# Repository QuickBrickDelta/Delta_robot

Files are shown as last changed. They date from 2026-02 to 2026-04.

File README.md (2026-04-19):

# QuickBrick Delta Robot 




> Projet de session S4 — Baccalauréat en Génie Robotique, Université de Sherbrooke.  
> Un système complet de tri automatisé par vision numérique et planification de trajectoire optimale.

Réalisé par  Domenic Coppola, Antoine Côté, Thierry Allen, Antoine Bolduc et Raphaël Gendron.

Utilisation de l'IA générative à des fins de déverminage et d'assistance à la conception.

---

##  Aperçu

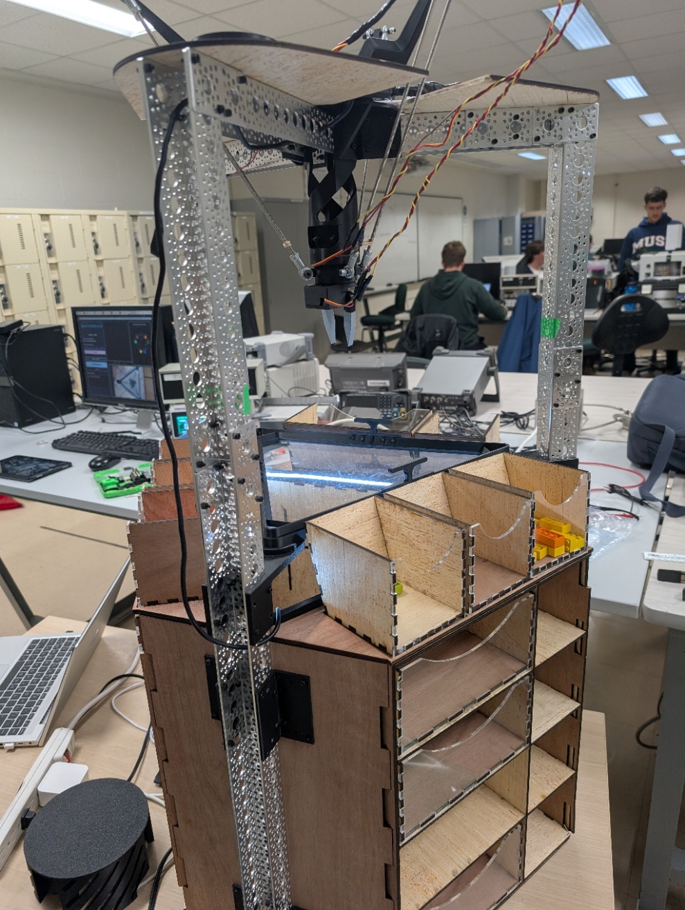
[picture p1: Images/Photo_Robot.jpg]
robot


| Interface Vision | Planification de Trajectoire |
|:---:|:---:|
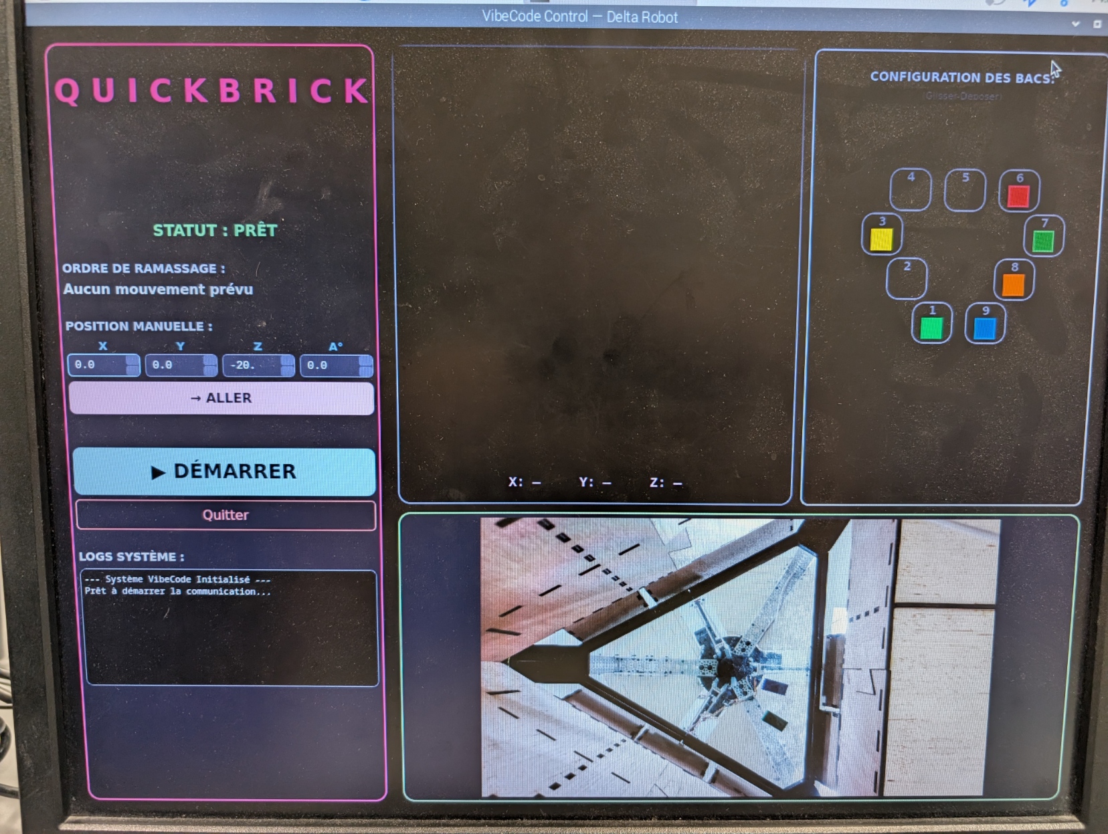
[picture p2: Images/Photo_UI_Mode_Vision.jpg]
vision
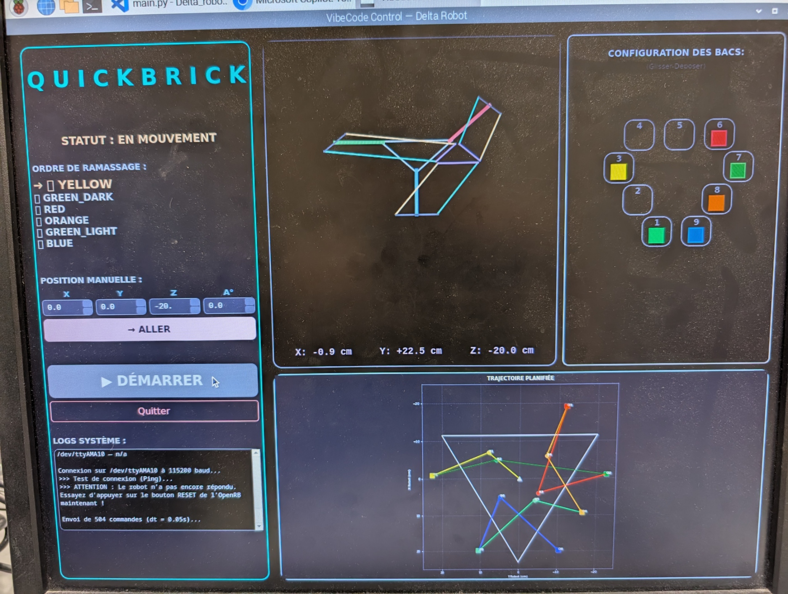
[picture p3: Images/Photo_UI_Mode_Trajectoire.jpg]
traj
|  |  |

---

##  Mise en route rapide

### 1. Installation du logiciel
Clonez le dépôt et installez les dépendances :
```bash
git clone https://github.com/votre-repo/Delta_robot.git
cd Delta_robot
pip install -r requirements.txt
```
Consultez le [Guide d'installation détaillé](docs/software_setup.md) pour la configuration du Raspberry Pi et de la caméra.

### 2. Matériel
Ce projet utilise des moteurs **Dynamixel XC430** et un contrôleur **OpenRB-150**.
Voir la [Documentation Matérielle](docs/hardware.md) pour le schéma de câblage et la liste des composants (BOM).

---

##  Architecture du projet

Le robot intègre plusieurs sous-systèmes travaillant en boucle fermée :

1.  **Vision Numérique** : Détection des blocs et conversion pixel → cm via homographie.
2.  **Planificateur** : Optimisation de l'ordre de tri par algorithme **Branch & Bound** (Problème du voyageur de commerce asymétrique).
3.  **Cinématique** : Modèle géométrique inverse pour le pilotage des 3 bras parallèles.
4.  **UI de Contrôle** : Visualisation 3D en temps réel et interface de configuration des bacs par "Drag & Drop".

###  Structure des dossiers
```
Delta_robot/
├── Arduino/            # Firmware C++ pour OpenRB-150
├── CAD/                # Fichiers CAD (STL et DXF) d'impression 3D et découpe laser
├── CinématiqueRobot/   # Modèles DGM/IGM & Interpolations
├── Communication/      # Protocole série Raspberry Pi ↔ Arduino
├── docs/               # Documentation détaillée (Hardware, Math, Setup)
├── Images/             # Captures et photos du système
├── Trajectoire/        # Algorithmes d'optimisation (BnB, TSP)
├── UI/                 # Interface PyQt6 (VibeCode UI)
└── VisionNumerique/    # Traitement d'image OpenCV & HSV
```

---

##  Documentation détaillée

*   [**Guide Matériel**](docs/hardware.md) : Liste des pièces, électronique et montage.
*   [**Fichiers CAD**](CAD/readme-cad.md) : Fichiers CAD des pièces destinées à l'impression 3D et la découpe laser.
*   [**Installation Logicielle**](docs/software_setup.md) : Configuration de l'environnement Python et flashage Arduino.
*   [**Mathématiques & Cinématique**](docs/kinematics.md) : Détails sur l'IGM et la planification de trajectoire.
*   [**Contribuer**](CONTRIBUTING.md) : Comment aider à améliorer le projet.

---

##  Licence

Ce projet est distribué sous la licence **MIT**. Voir le fichier [LICENSE.txt](LICENSE.txt) pour plus de détails.

---

*Université de Sherbrooke — GRO S4 — 2025-2026*

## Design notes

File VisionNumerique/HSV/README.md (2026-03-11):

## VisionNumerique/HSV

Objectif: regrouper les scripts dont la stratégie couleur est **majoritairement HSV**
(plus robuste aux variations de luminosité que des seuils RGB).

### Calibration HSV (ROI)

Lance:

```bash
python VisionNumerique/HSV/calibrate_hsv_ranges.py
```

Usage:
- **Drag** une ROI sur un bloc
- **1..9** assigne la dernière ROI à une couleur (ex: `1=red`, `2=green`, ...)
- **e** exporte `hsv_ranges.json` dans ce dossier
- **r** reset, **q/ESC** quitter

Le fichier `hsv_ranges.json` contient des plages HSV OpenCV \(H 0..179\) sous forme
de liste d'intervalles `[[loHSV],[hiHSV]]`. Le rouge peut être exporté en **2 intervalles** (wrap autour de 0).

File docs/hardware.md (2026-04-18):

# Documentation Matérielle

Ce guide couvre l'assemblage physique, l'électronique et la liste des composants (BOM) du Robot Delta.

## Liste des composants à acheter (BOM)
| Image | Composant | Description | Quantité |
|---|---|---|---|
|  | **Moteurs** | Dynamixel XC430-W240 (ou équivalent) | 3 |
|  | **Contrôleur** | OpenRB-150 (compatible Arduino) | 1 |
|  | **Alimentation** | Bloc DC 12V 5A | 1 |
|  | **Joint à rotule** | Joint à rotule fileté M4 | 12 |
|  | **Tiges** | Tige filetée M4-30mm | 6 |
|  | **Caméra** | Caméra module 3 Raspberry Pi | 1 |
|  | **Servo moteur SG90** | Servo moteur SG90 | 2 |
|  | **Bande lumineuse de DEL** | À connexion USB (5V), intensité variable | 1 |
|  | **Attache à tiroir** | Attache à tiroir Richelieu | 1 |
|  | **Fil caméra** | Fil 22 pin à 15 pin pour caméra Raspberry Pi | 1 |
|  | **Extrudé 9 pouces** | Extrudé 9 pouces | 3 |
|  | **Extrudé 12 pouces** | Extrudé 12 pouces | 3 |
|  | **Extrudé 24 pouces** | Extrudé 24 pouces | 3 |
|  | **Plaque pour extrudés** | Plaque connecteur pour extrudés | 12 |
|  | **Convertisseur buck** | Convertisseur buck 12V à 5V | 1 |
|  | **Feuille d'acrylique** | Plaque d'acrylique 3mm | 1 |
|  | **Plaques de bois (découpe laser)** | Plaques de bois 4.3mm — utiliser les retailles lorsque possible | 8 |

## Schéma de câblage

1.  **Moteurs Dynamixel** : Connectez les 3 moteurs en "daisy-chain" et reliez-les à l'un des ports Dynamixel de l'OpenRB-150.
2.  **Alimentation** : Connectez le bloc 12V au bornier de l'OpenRB-150. **ATTENTION** : Vérifiez la polarité.
3.  **Communication** : Reliez l'OpenRB-150 au Raspberry Pi (ou PC) via un câble USB-C.

Schéma électrique

Schéma Électrique
*(Fichier draw.io)*

## Étapes d'assemblage

1.  **Base** : Montez les 3 moteurs Dynamixel à 120° sur le châssis principal.
2.  **Parallélogrammes** : Assemblez les 6 tiges parallèles à l'aide des joints à rotule.
3.  **Effecteur** : Montez l'effecteur final (pince) et connectez le signal du servo aux broches de l'OpenRB-150.
4.  **Calibration** : Assurez-vous que les moteurs sont à 0° (horizontaux) avant de fixer les bras principaux.

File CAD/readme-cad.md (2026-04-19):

# Fichiers CAD — QuickBrick Delta

Les fichiers CAD de ce projet ont été conçus dans [OnShape](https://cad.onshape.com/).

> [Voir l'assemblage complet](https://cad.onshape.com/documents/0e918514191409c2a18572ab/w/21e7121afbe0440ffe943c21/e/87bd8cfb125acff7d4804a25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)

---

## Formats disponibles

- **STL** — Prêt pour l'impression 3D
- **DXF** — Prêt pour la découpe laser

---

## Impression 3D

### Bras robotique



| Image | Pièce | Fichier STL | Matériau recommandé | Remplissage | Quantité |
|---|---|---|---|---|---|
|  | Plateforme supérieure | [plateforme-superieure.stl](STL/assemblage-robot/plateforme-superieure.stl) | PLA | 15% | 1 |
|  | Coque | [coque.stl](STL/assemblage-robot/coque.stl) | PLA | 15% | 1 |
|  | Système de mise à l'origine | [mise-a-lorigine.stl](STL/assemblage-robot/mise-a-lorigine.stl) | PLA | 15% | 1 |
|  | Anneau bearing | [anneau-bearing.stl](STL/assemblage-robot/anneau-bearing.stl) | PLA | 15% | 3 |
|  | Clip bearing | [clip-bearing.stl](STL/assemblage-robot/clip-bearing.stl) | PLA | 15% | 3 |
|  | Biceps | [biceps.stl](STL/assemblage-robot/biceps.stl) | PLA | 15% | 3 |
|  | Espaceur | [espaceur.stl](STL/assemblage-robot/espaceur.stl) | PLA | 15% | 24 |

---

### Plaque d'acrylique



| Image | Pièce | Fichier STL | Matériau recommandé | Remplissage | Quantité |
|---|---|---|---|---|---|
|  | Supports à plaque d'acrylique | [support-plaque-acrylique.stl](STL/plaque-acrylique/support-plaque-acrylique.stl) | PLA | 15% | 3 |
|  | Bordure | [bordure.stl](STL/plaque-acrylique/bordure.stl) | PLA | 15% | 3 |
|  | Poignée | [poignee.stl](STL/plaque-acrylique/poignee.stl) | PLA | 15% | 3 |

---

### Pince



| Image | Pièce | Fichier STL | Matériau recommandé | Remplissage | Quantité |
|---|---|---|---|---|---|
|  | Support à servo de poignet | [support-servo-poignet.stl](STL/pince/support-servo-poignet.stl) | PLA | 15% | 1 |
|  | Support à servo de pince | [support-servo-pince.stl](STL/pince/support-servo-pince.stl) | PLA | 15% | 1 |
|  | Plaque pour support à servo de pince | [plaque-support-servo-pince.stl](STL/pince/plaque-support-servo-pince.stl) | PLA | 15% | 1 |
|  | Washer pour pince | [washer-pince.stl](STL/pince/washer-pince.stl) | PLA | 15% | 1 |
|  | Pince 1 | [pince-1.stl](STL/pince/pince-1.stl) | PLA | 15% | 1 |
|  | Pince 2 | [pince-2.stl](STL/pince/pince-2.stl) | PLA | 15% | 1 |
|  | Embouts de pince | [embouts-pince.stl](STL/pince/embouts-pince.stl) | TPU | 15% | 2 |
|  | Couvercle de pince avec couronne pour mise à l'origine | [couvercle-pince-couronne.stl](STL/pince/couvercle-pince-couronne.stl) | PLA | 15% | 1 |

---

### Anneau de lumière



| Image | Pièce | Fichier STL | Matériau recommandé | Remplissage | Quantité |
|---|---|---|---|---|---|
|  | Anneau de lumière - Pièce 1 | [anneau-lumiere-1.stl](STL/anneau-lumiere/anneau-lumiere-1.stl) | PLA | 15% | 6 |
|  | Anneau de lumière - Pièce 2 | [anneau-lumiere-2.stl](STL/anneau-lumiere/anneau-lumiere-2.stl) | PLA | 15% | 6 |
|  | Anneau de lumière - Pièce 3 | [anneau-lumiere-3.stl](STL/anneau-lumiere/anneau-lumiere-3.stl) | PLA | 15% | 6 |

---

### Attaches de caméra et Raspberry Pi



| Image | Pièce | Fichier STL | Matériau recommandé | Remplissage | Quantité |
|---|---|---|---|---|---|
|  | Attache caméra | [attache-camera.stl](STL/autres/attache-camera.stl) | PLA | 15% | 1 |
|  | Attache Raspberry Pi | [attache-raspberry-pi.stl](STL/autres/attache-raspberry-pi.stl) | PLA | 15% | 1 |

---

## Découpe laser

### Étagère



| Image | Pièce | Fichier STL | Fichier DXF | Matériau | Épaisseur | Quantité |
|---|---|---|---|---|---|---|
|  | Montant de support | [montant-support.stl](STL/etagere/montant-support.stl) | [montant-support.dxf](DXF/etagere/montant-support.dxf) | Bois | 4.3mm | 2 |
|  | Montant de support avec trou | [montant-support-trou.stl](STL/etagere/montant-support-trou.stl) | [montant-support-trou.dxf](DXF/etagere/montant-support-trou.dxf) | Bois | 4.3mm | 1 |
|  | Montant droite | [montant-droite.stl](STL/etagere/montant-droite.stl) | [montant-droite.dxf](DXF/etagere/montant-droite.dxf) | Bois | 4.3mm | 3 |
|  | Montant gauche | [montant-gauche.stl](STL/etagere/montant-gauche.stl) | [montant-gauche.dxf](DXF/etagere/montant-gauche.dxf) | Bois | 4.3mm | 3 |
|  | Tablette 1 | [tablette-1.stl](STL/etagere/tablette-1.stl) | [tablette-1.dxf](DXF/etagere/tablette-1.dxf) | Bois | 4.3mm | 7 |
|  | Tablette du haut | [tablette-haut.stl](STL/etagere/tablette-haut.stl) | [tablette-haut.dxf](DXF/etagere/tablette-haut.dxf) | Bois | 4.3mm | 3 |
|  | Tablette du fond | [tablette-fond.stl](STL/etagere/tablette-fond.stl) | [tablette-fond.dxf](DXF/etagere/tablette-fond.dxf) | Bois | 4.3mm | 3 |
|  | Plaque de plancher secondaire | [plaque-plancher-secondaire.stl](STL/etagere/plaque-plancher-secondaire.stl) | [plaque-plancher-secondaire.dxf](DXF/etagere/plaque-plancher-secondaire.dxf) | Bois | 4.3mm | 3 |
|  | Plaque de plancher au sol | [plaque-plancher-sol.stl](STL/etagere/plaque-plancher-sol.stl) | [plaque-plancher-sol.dxf](DXF/etagere/plaque-plancher-sol.dxf) | Bois | 4.3mm | 3 |
|  | Séparateur de bacs | [separateur-bacs.stl](STL/etagere/separateur-bacs.stl) | [separateur-bacs.dxf](DXF/etagere/separateur-bacs.dxf) | Bois | 4.3mm | 3 |
|  | Séparateur long | [separateur-long.stl](STL/etagere/separateur-long.stl) | [separateur-long.dxf](DXF/etagere/separateur-long.dxf) | Bois | 4.3mm | 2 |
|  | Séparateur court | [separateur-court.stl](STL/etagere/separateur-court.stl) | [separateur-court.dxf](DXF/etagere/separateur-court.dxf) | Bois | 4.3mm | 1 |
|  | Fond - partie 1 gauche | [fond-partie-1-gauche.stl](STL/etagere/fond-partie-1-gauche.stl) | [fond-partie-1-gauche.dxf](DXF/etagere/fond-partie-1-gauche.dxf) | Bois | 4.3mm | 1 |
|  | Fond - partie 2 gauche | [fond-partie-2-gauche.stl](STL/etagere/fond-partie-2-gauche.stl) | [fond-partie-2-gauche.dxf](DXF/etagere/fond-partie-2-gauche.dxf) | Bois | 4.3mm | 1 |
|  | Fond - partie 1 droite | [fond-partie-1-droite.stl](STL/etagere/fond-partie-1-droite.stl) | [fond-partie-1-droite.dxf](DXF/etagere/fond-partie-1-droite.dxf) | Bois | 4.3mm | 1 |
|  | Fond - partie 2 droite | [fond-partie-2-droite.stl](STL/etagere/fond-partie-2-droite.stl) | [fond-partie-2-droite.dxf](DXF/etagere/fond-partie-2-droite.dxf) | Bois | 4.3mm | 1 |
|  | Fond - partie 1 arrière | [fond-partie-1-arriere.stl](STL/etagere/fond-partie-1-arriere.stl) | [fond-partie-1-arriere.dxf](DXF/etagere/fond-partie-1-arriere.dxf) | Bois | 4.3mm | 1 |
|  | Fond - partie 2 arrière | [fond-partie-2-arriere.stl](STL/etagere/fond-partie-2-arriere.stl) | [fond-partie-2-arriere.dxf](DXF/etagere/fond-partie-2-arriere.dxf) | Bois | 4.3mm | 1 |

### Bac simple



| Image | Pièce | Fichier STL | Fichier DXF | Matériau | Épaisseur | Quantité |
|---|---|---|---|---|---|---|
|  | Fond | [bac-simple-fond.stl](STL/bac-simple/bac-simple-fond.stl) | [bac-simple-fond.dxf](DXF/bac-simple/bac-simple-fond.dxf) | Bois | 4.3mm | 1 |
|  | Mur | [bac-simple-mur.stl](STL/bac-simple/bac-simple-mur.stl) | [bac-simple-mur.dxf](DXF/bac-simple/bac-simple-mur.dxf) | Bois | 4.3mm | 2 |
|  | Avant | [bac-simple-avant.stl](STL/bac-simple/bac-simple-avant.stl) | [bac-simple-avant.dxf](DXF/bac-simple/bac-simple-avant.dxf) | Acrylique | 3mm | 1 |
|  | Arrière | [bac-simple-arriere.stl](STL/bac-simple/bac-simple-arriere.stl) | [bac-simple-arriere.dxf](DXF/bac-simple/bac-simple-arriere.dxf) | Bois | 4.3mm | 1 |

---

### Bac double



| Image | Pièce | Fichier STL | Fichier DXF | Matériau | Épaisseur | Quantité |
|---|---|---|---|---|---|---|
|  | Fond | [bac-double-fond.stl](STL/bac-double/bac-double-fond.stl) | [bac-double-fond.dxf](DXF/bac-double/bac-double-fond.dxf) | Bois | 4.3mm | 1 |
|  | Mur | [bac-double-mur.stl](STL/bac-double/bac-double-mur.stl) | [bac-double-mur.dxf](DXF/bac-double/bac-double-mur.dxf) | Bois | 4.3mm | 2 |
|  | Avant | [bac-double-avant.stl](STL/bac-double/bac-double-avant.stl) | [bac-double-avant.dxf](DXF/bac-double/bac-double-avant.dxf) | Acrylique | 3mm | 1 |
|  | Arrière | [bac-double-arriere.stl](STL/bac-double/bac-double-arriere.stl) | [bac-double-arriere.dxf](DXF/bac-double/bac-double-arriere.dxf) | Bois | 4.3mm | 1 |

---

## Notes

- Toutes les dimensions sont en millimètres.
- L'assemblage est effectué avec des vis M3 de longueur variée.

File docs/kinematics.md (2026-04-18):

# Cinématique du Robot Delta

Ce document explique le modèle mathématique utilisé pour contrôler le Robot Delta à 3 bras.

## Système de coordonnées

- **Origine (0,0,0)** : Centre géométrique de la plaque de base supérieure.
- **Axe X** : Pointe vers le premier bras.
- **Axe Z** : Pointe vers le bas (les valeurs négatives augmentent à mesure que le robot descend).

## Cinématique Inverse (IGM)

La cinématique inverse convertit une position `(P_x, P_y, P_z)` souhaitée de l'effecteur en 3 angles moteurs `(theta_1, theta_2, theta_3)`.

Le robot delta se compose de 3 chaînes identiques. Pour chaque chaîne, nous trouvons l'intersection entre :
1.  Le cercle tracé par le bras supérieur.
2.  La sphère tracée par les tiges parallèles inférieures autour du point de fixation de l'effecteur.

La solution est calculée analytiquement dans `CinématiqueRobot/Cinematique_delta3bras.py`.

Schéma Cinématique
*(Prochainement : Diagrammes détaillés des longueurs de bras f, e, rf et re)*

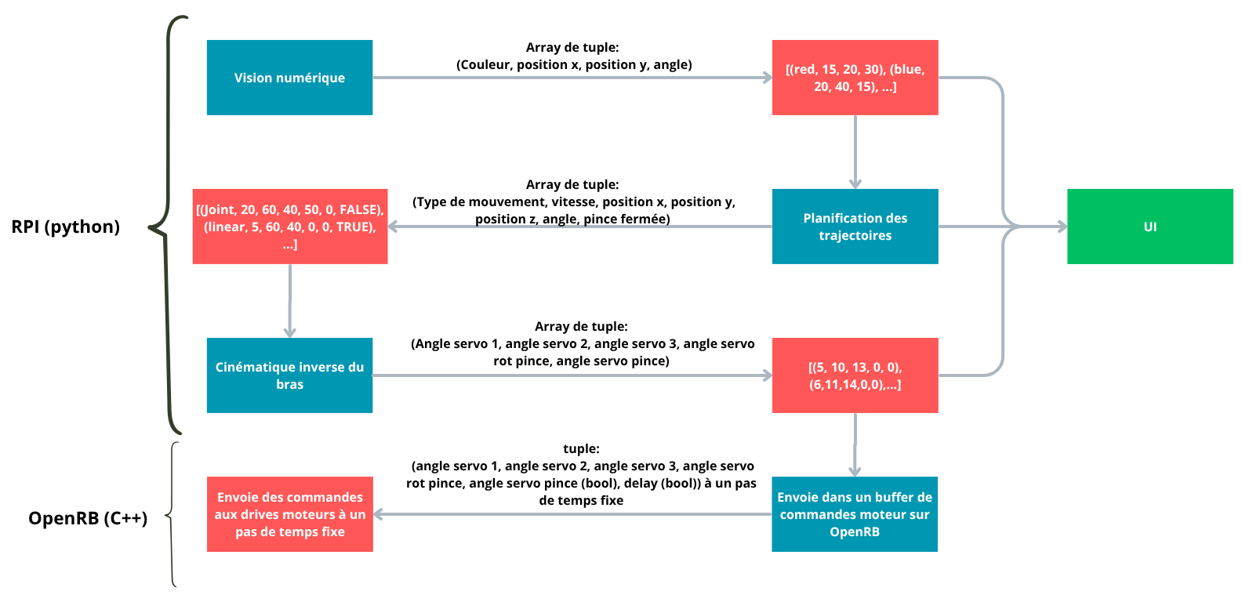
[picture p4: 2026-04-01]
docs/img/OpenRB.png

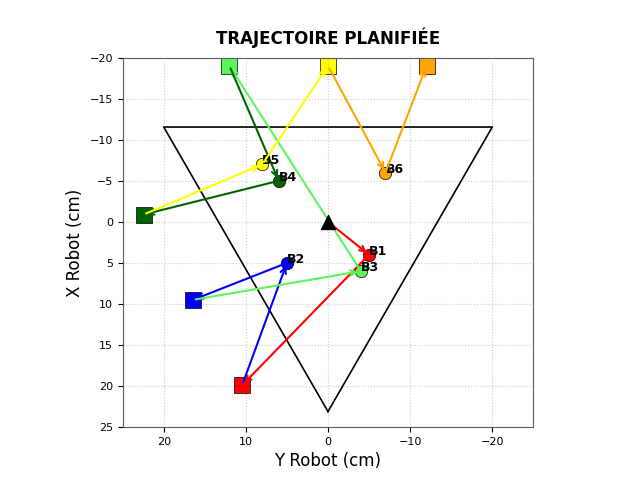
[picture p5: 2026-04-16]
docs/img/Plot_trajectoire_ordre.png

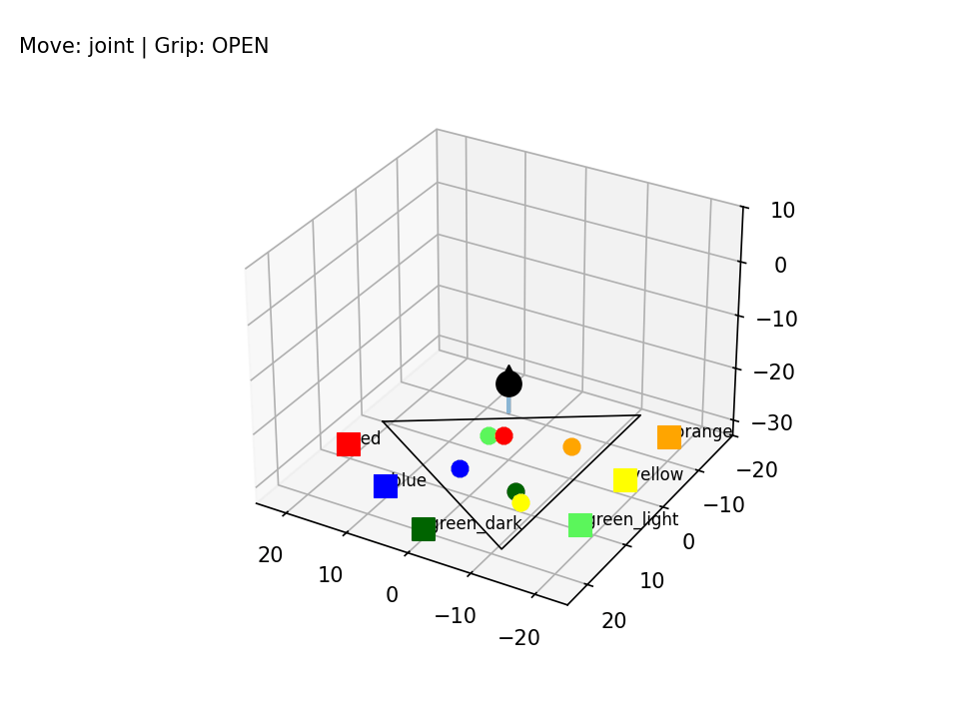
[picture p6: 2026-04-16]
docs/img/simulation_robot.gif

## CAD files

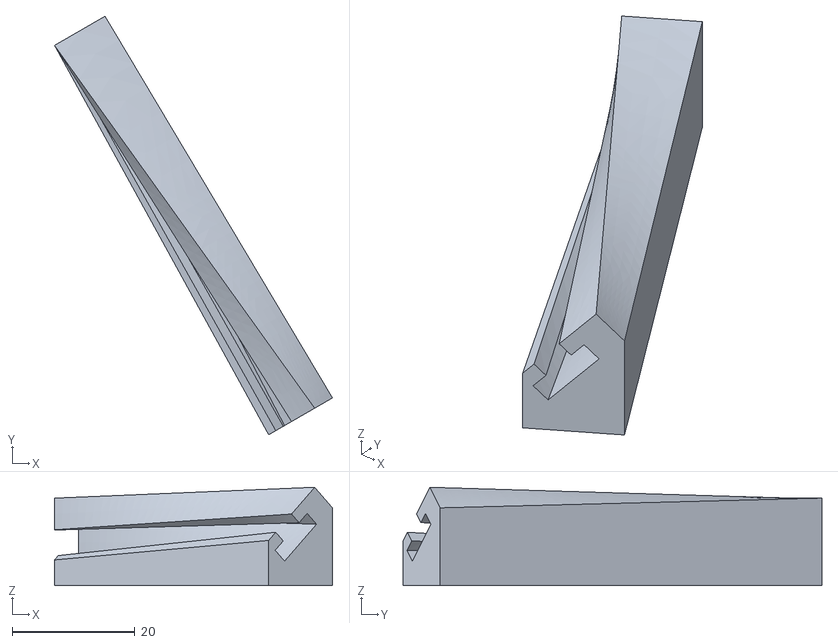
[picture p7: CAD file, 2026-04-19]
CAD/STL/anneau-lumiere/anneau-lumiere-2.stl
45.3 x 68.1 x 16.0

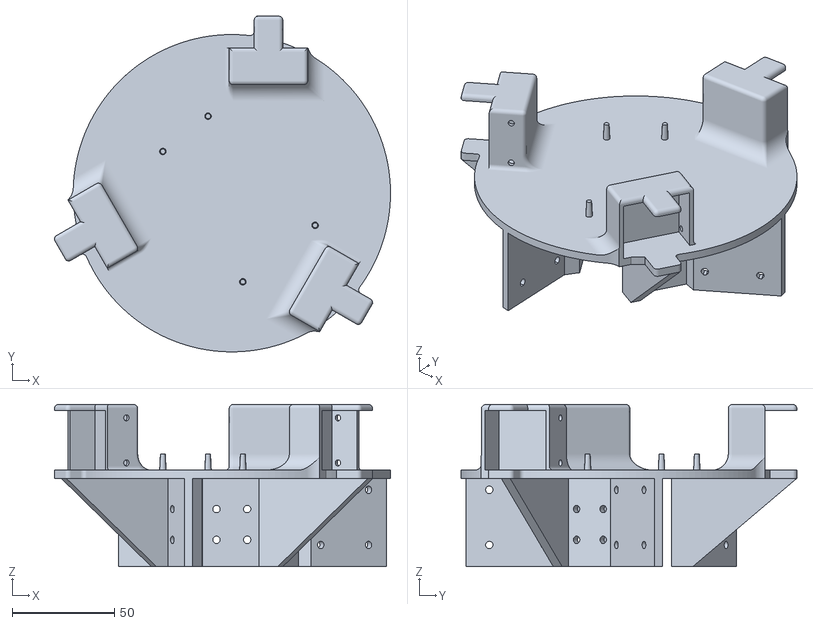
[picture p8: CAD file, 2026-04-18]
CAD/STL/assemblage-robot/plateforme-superieure.stl
164.1 x 164.0 x 79.2

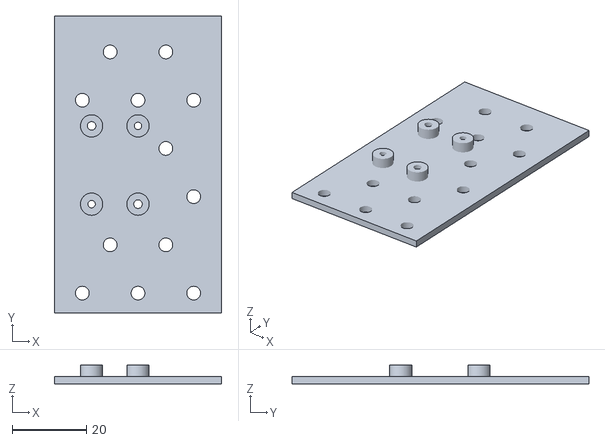
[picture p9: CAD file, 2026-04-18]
CAD/STL/autres/attache-camera.stl
45.0 x 80.0 x 5.00

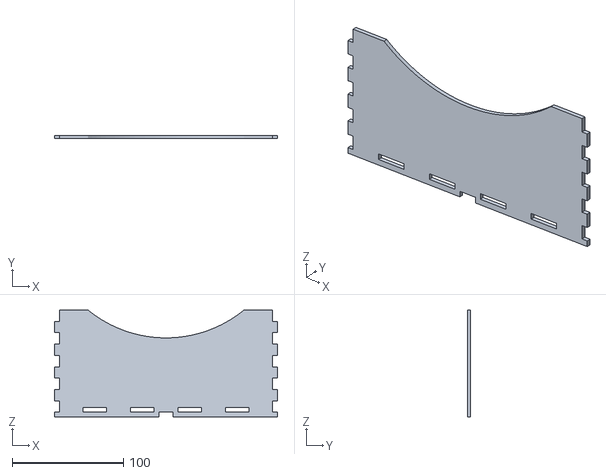
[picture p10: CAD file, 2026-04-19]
CAD/STL/bac-double/bac-double-avant.stl
200.3 x 3.00 x 96.0

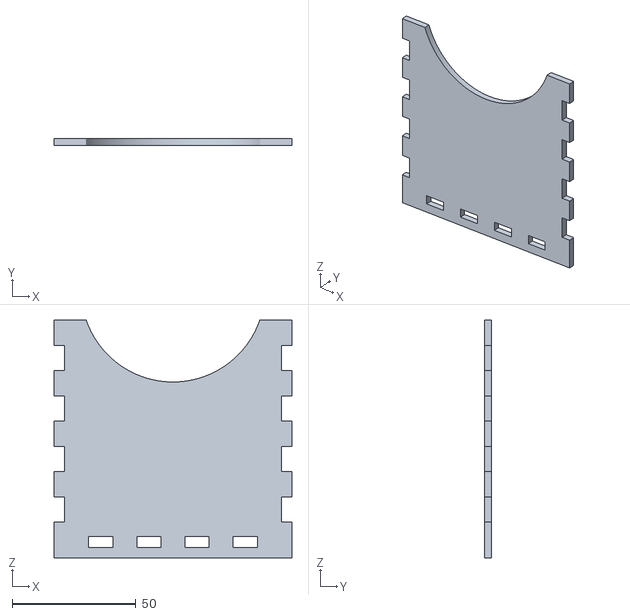
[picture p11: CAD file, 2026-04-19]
CAD/STL/bac-simple/bac-simple-avant.stl
96.0 x 3.00 x 96.0

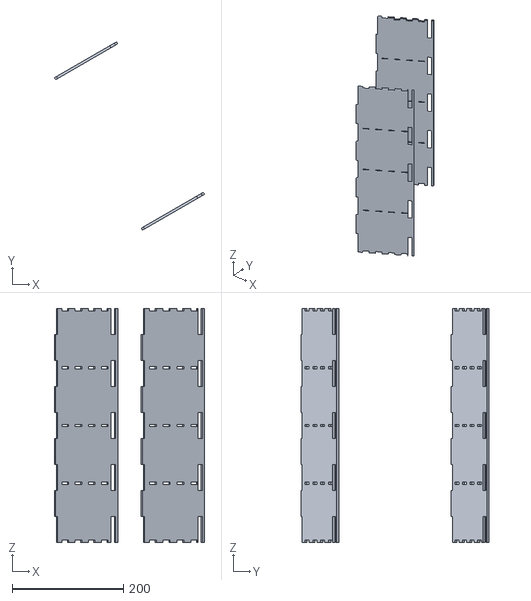
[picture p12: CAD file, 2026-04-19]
CAD/STL/etagere/montant-gauche.stl
270.6 x 339.4 x 421.5

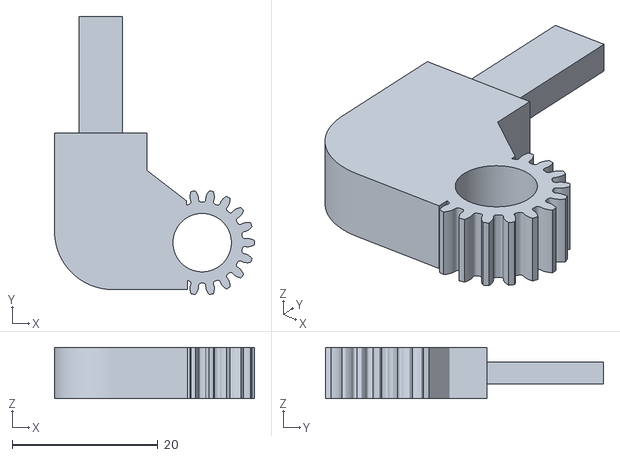
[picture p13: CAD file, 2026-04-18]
CAD/STL/pince/pince-2.stl
27.4 x 38.1 x 7.05

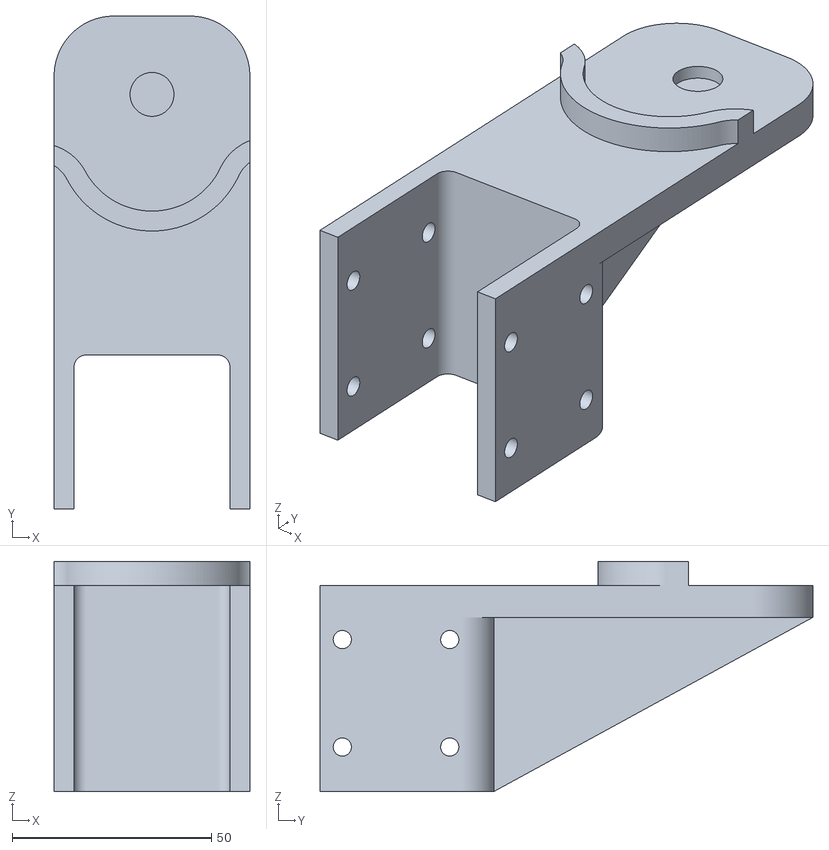
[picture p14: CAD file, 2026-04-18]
CAD/STL/plaque-acrylique/support-plaque-acrylique.stl
49.1 x 123.6 x 57.7

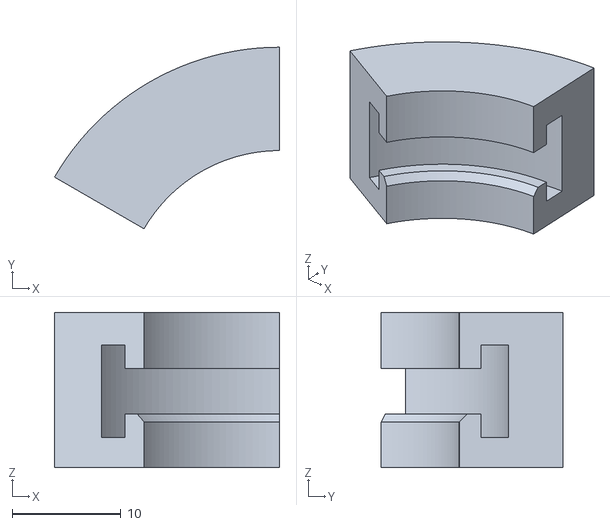
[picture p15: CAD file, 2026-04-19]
CAD/STL/anneau-lumiere/anneau-lumiere-3.stl
20.7 x 16.7 x 14.3

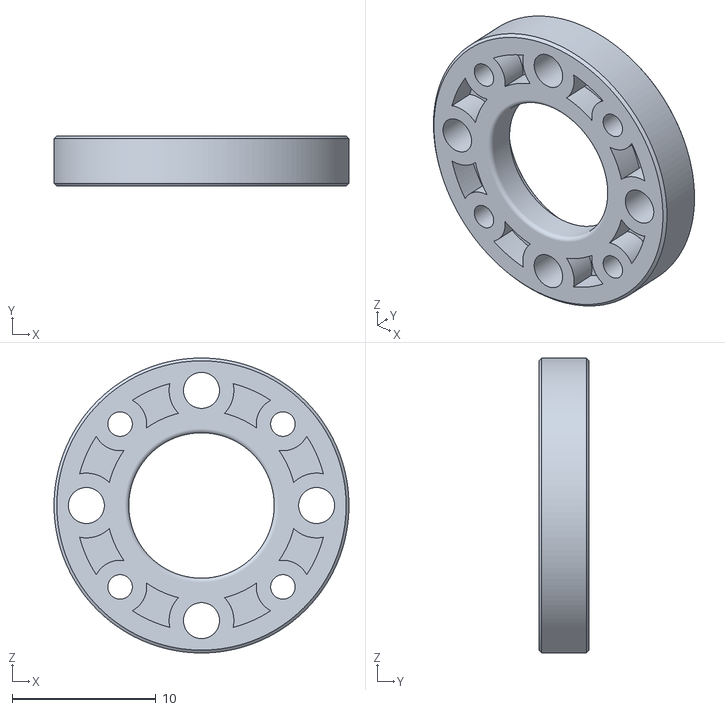
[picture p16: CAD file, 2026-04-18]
CAD/STL/assemblage-robot/anneau-bearing.stl
20.5 x 3.50 x 20.5

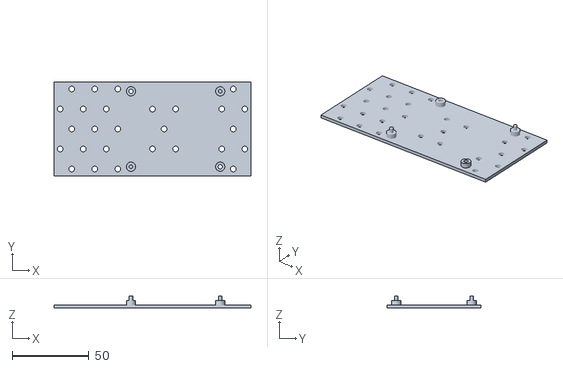
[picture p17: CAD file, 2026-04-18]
CAD/STL/autres/attache-raspberry-pi.stl
128.0 x 61.0 x 8.00

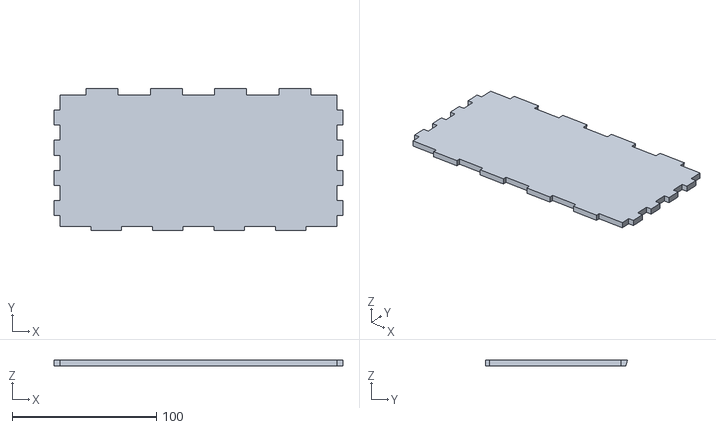
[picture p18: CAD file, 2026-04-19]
CAD/STL/bac-double/bac-double-fond.stl
200.3 x 98.6 x 4.30

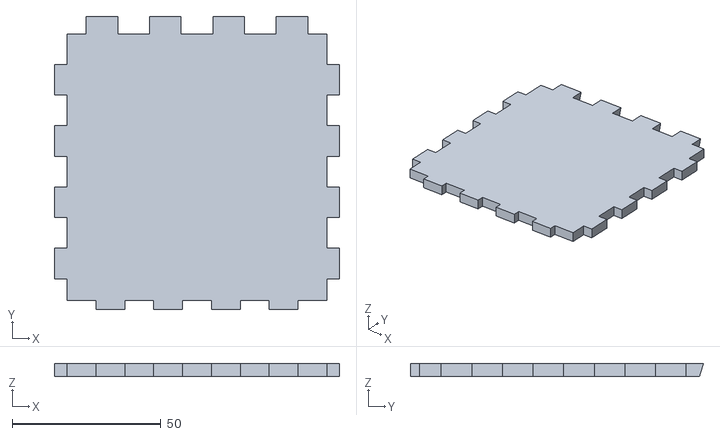
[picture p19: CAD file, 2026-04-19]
CAD/STL/bac-simple/bac-simple-fond.stl
96.0 x 98.6 x 4.30

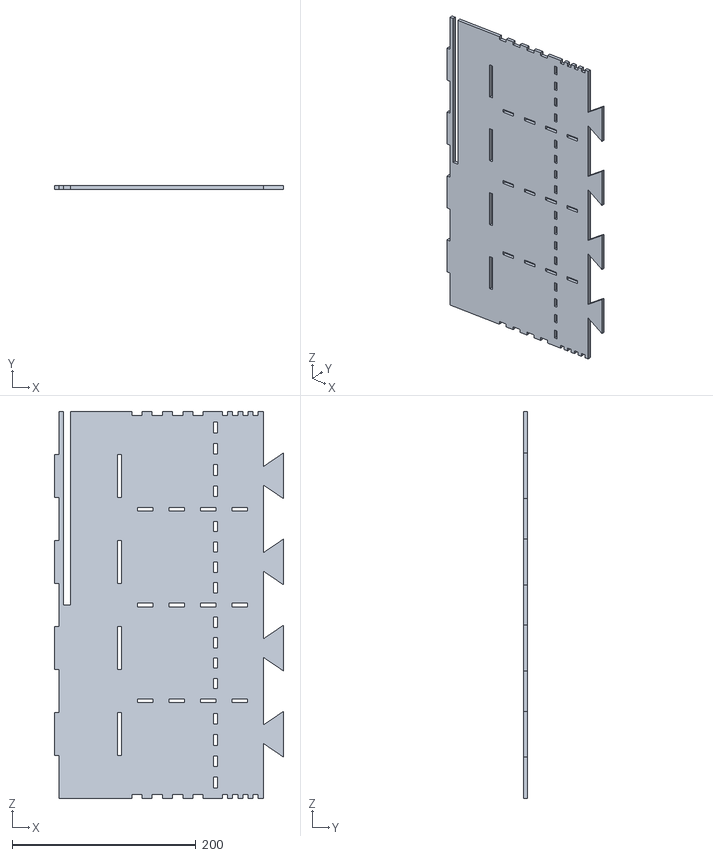
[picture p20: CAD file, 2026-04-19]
CAD/STL/etagere/fond-partie-2-gauche.stl
249.6 x 4.30 x 421.5

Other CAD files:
CAD/STL/plaque-acrylique/poignee.stl
CAD/STL/anneau-lumiere/anneau-lumiere-1.stl
CAD/STL/assemblage-robot/mise-a-lorigine.stl
CAD/STL/bac-double/bac-double-mur.stl
CAD/DXF/bac-double/bac-double-arriere.dxf
CAD/DXF/bac-double/bac-double-avant.dxf
CAD/DXF/bac-double/bac-double-fond.dxf
CAD/DXF/bac-double/bac-double-mur.dxf
CAD/DXF/bac-simple/bac-simple-arriere.dxf
CAD/DXF/bac-simple/bac-simple-avant.dxf
CAD/DXF/bac-simple/bac-simple-fond.dxf
CAD/DXF/bac-simple/bac-simple-mur.dxf
CAD/DXF/etagere/fond-partie-1-arriere.dxf
CAD/DXF/etagere/fond-partie-1-droite.dxf
CAD/DXF/etagere/fond-partie-1-gauche.dxf
CAD/DXF/etagere/fond-partie-2-arriere.dxf
CAD/DXF/etagere/fond-partie-2-droite.dxf
CAD/DXF/etagere/fond-partie-2-gauche.dxf
CAD/DXF/etagere/montant-droite.dxf
CAD/DXF/etagere/montant-gauche.dxf
CAD/DXF/etagere/montant-support-trou.dxf
CAD/DXF/etagere/montant-support.dxf
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

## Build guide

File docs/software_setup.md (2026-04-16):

# Guide d'Installation Logicielle

Suivez ces étapes pour configurer l'environnement de contrôle du Robot Delta.

## 1. Prérequis

- **Python 3.10+** installé sur votre système.
- **Arduino IDE** (ou VS Code + PlatformIO) pour flasher le firmware.

## 2. Environnement Python (PC ou Raspberry Pi)

Il est fortement recommandé d'utiliser un environnement virtuel :

```bash
# Créer l'environnement
python -m venv venv

# Activer l'environnement
# Sur Windows :
venv\Scripts\activate
# Sur Linux/macOS :
source venv/bin/activate

# Installer les dépendances
pip install -r requirements.txt
```

## 3. Configuration du Firmware Arduino

1.  Ouvrez `Arduino/OpenRB_DeltaRobot/OpenRB_DeltaRobot.ino` dans l'IDE Arduino.
2.  Installez les bibliothèques **DynamixelShield** et le gestionnaire de cartes **OpenRB** si ce n'est pas déjà fait.
3.  Connectez votre OpenRB-150 et téléversez le code.

## 4. Configuration de la Caméra (Linux/Raspberry Pi)

Si vous utilisez un Raspberry Pi avec la caméra officielle, assurez-vous que GStreamer est installé :

```bash
sudo apt-get install libgstreamer1.0-dev libgstreamer-plugins-base1.0-dev gstreamer1.0-plugins-bad gstreamer1.0-libav
```

L'application utilise un pipeline optimisé pour une détection à faible latence.

## 5. Lancer l'Application

Lancez l'interface principale depuis la racine du projet :

```bash
python UI/main.py
```

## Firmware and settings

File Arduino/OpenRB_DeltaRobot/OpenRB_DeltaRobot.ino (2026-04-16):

#include <Dynamixel2Arduino.h>
#include <Servo.h>

// ================================
// Configuration
// ================================
#define DEBUG_SERIAL Serial
#define DXL_SERIAL Serial1

const uint8_t ID_M1 = 1;
const uint8_t ID_M2 = 2;
const uint8_t ID_M3 = 3;

// ================================
// CALIBRATION — Auto au démarrage
// ================================
// Au boot, le robot doit être en position HOME (0, 0, -20)
// L'Arduino lit les positions actuelles comme offsets.
// THETA_CALIB = angle des moteurs à la position (0, 0, -20)
int32_t REPOS_M1 = 0;
int32_t REPOS_M2 = 0;
int32_t REPOS_M3 = 0;

// Angle moteurs à la position de calibration (0, 0, -20)
const float THETA_CALIB = 2.2897f; // rad (~131.2°)

// Ticks par radian (4095 ticks / tour complet)
const float TICKS_PER_RAD =
    4096.0f / (2.0f * PI); // 4096 pour Dynamixel (0-4095)

// ================================
// Vitesse et pince (servo PWM)
// ================================
const uint32_t PROFILE_VELOCITY = 0; // 0 = Vitesse max (suivi pur Python)
const uint32_t PROFILE_ACCELERATION =
    0;                         // 0 = Accélération max (suivi pur Python)
const int SERVO_PINCE_PIN = 3; // Pin PWM du servo pince
const int SERVO_WRIST_PIN = 5; // Pin PWM du servo poignet
const int PULSE_OUVERTE = 1845;
const int PULSE_FERMEE = 2030;
const int PULSE_WRIST_0_DEG = 1700; // Valeur calibrée pour 0° (neutre)
const int PULSE_WRIST_90_DEG = 550; // Valeur calibrée pour +90°

Dynamixel2Arduino dxl(DXL_SERIAL);
Servo pinceServo;
Servo wristServo;

// ================================
// Variables
// ================================
const size_t LINE_BUF_SIZE = 128; // Augmenté pour éviter les débordements
char lineBuf[LINE_BUF_SIZE];
size_t linePos = 0;

float lastTheta1 = 0.0f;
float lastTheta2 = 0.0f;
float lastTheta3 = 0.0f;
bool lastPince = false;
float lastWristAngle = 0.0f; // Nouvel angle en degrés

bool currentPinceState = false;    // État réel actuel de la pince
float currentWristAngle = -999.0f; // Pour ne bouger que sur changement
bool newCommand = false;
uint32_t cmdCount = 0;
uint32_t lastErrorCheck = 0;

// ================================
// Diagnostic - Lecture des alarmes
// ================================
void checkHardErrors() {
  uint8_t ids[] = {ID_M1, ID_M2, ID_M3};

  for (int i = 0; i < 3; i++) {
    DEBUG_SERIAL.print("Diagnostic Moteur ");
    DEBUG_SERIAL.print(ids[i]);
    DEBUG_SERIAL.print(" : ");

    if (dxl.ping(ids[i])) {
      uint16_t model = dxl.getModelNumber(ids[i]);
      uint8_t error = dxl.readControlTableItem(
          ControlTableItem::HARDWARE_ERROR_STATUS, ids[i]);

      DEBUG_SERIAL.print("Connecté (Modèle: ");
      DEBUG_SERIAL.print(model);
      DEBUG_SERIAL.print(") - Erreur: 0x");
      DEBUG_SERIAL.println(error, HEX);

      if (error > 0) {
        DEBUG_SERIAL.print("!! ALARM: M");
        DEBUG_SERIAL.print(ids[i]);
        DEBUG_SERIAL.println(" !!");
      }
    } else {
      DEBUG_SERIAL.println("NON TROUVÉ sur le bus !");
    }
  }
}

// ================================
// Conversion angle -> ticks
// ================================
// tick = REPOS - (theta - THETA_CALIB) * TICKS_PER_RAD
// Au boot (theta == THETA_CALIB) → delta = 0 → position = REPOS ✓

int32_t thetaToTicks(float theta_rad, int32_t repos_offset) {
  // theta_rad est en RADIANS (reçu du Python)
  // tick = REPOS - (theta - THETA_CALIB) * TICKS_PER_RAD
  return repos_offset - (int32_t)((theta_rad - THETA_CALIB) * TICKS_PER_RAD);
}

// ================================
// Setup
// ================================
void setup() {
  DEBUG_SERIAL.begin(115200);
  DEBUG_SERIAL.begin(115200);
  // On ne bloque pas indéfiniment si le PC n'est pas prêt
  uint32_t startWait = millis();
  while (!DEBUG_SERIAL && (millis() - startWait < 1000)) {
    ;
  }

  DXL_SERIAL.begin(57600);
  dxl.begin(57600);
  dxl.setPortProtocolVersion(2.0);

  // 1) Lire les positions actuelles AVANT d'activer le torque
  //    → Le robot doit être en position z_table (0, 0, -40)
  REPOS_M1 = dxl.getPresentPosition(ID_M1);
  REPOS_M2 = dxl.getPresentPosition(ID_M2);
  REPOS_M3 = dxl.getPresentPosition(ID_M3);

  DEBUG_SERIAL.println("=== OpenRB Delta Robot ===");
  DEBUG_SERIAL.println(">> AUTO-CALIBRATION <<");
  DEBUG_SERIAL.print("Repos lu: M1=");
  DEBUG_SERIAL.print(REPOS_M1);
  DEBUG_SERIAL.print(" M2=");
  DEBUG_SERIAL.print(REPOS_M2);
  DEBUG_SERIAL.print(" M3=");
  DEBUG_SERIAL.println(REPOS_M3);

  // 2) Configurer les moteurs Dynamixel (3 bras)
  uint8_t ids[] = {ID_M1, ID_M2, ID_M3};
  for (int i = 0; i < 3; i++) {
    dxl.torqueOff(ids[i]);
    dxl.setOperatingMode(ids[i], OP_EXTENDED_POSITION);
    dxl.writeControlTableItem(ControlTableItem::PROFILE_VELOCITY, ids[i],
                              PROFILE_VELOCITY);
    dxl.writeControlTableItem(ControlTableItem::PROFILE_ACCELERATION, ids[i],
                              PROFILE_ACCELERATION);
    dxl.torqueOn(ids[i]);
  }

  // 3) Vérifier si les moteurs sont en alarme (voyant rouge)
  checkHardErrors();

  // 3) Configurer les servos (PWM microseconds)
  pinceServo.attach(SERVO_PINCE_PIN, 500, 2500);
  pinceServo.writeMicroseconds(PULSE_OUVERTE);

  wristServo.attach(SERVO_WRIST_PIN, 0, 3600);
  wristServo.writeMicroseconds(PULSE_WRIST_0_DEG);

  DEBUG_SERIAL.print("Velocity=");
  DEBUG_SERIAL.println(PROFILE_VELOCITY);
  DEBUG_SERIAL.println(
      "Pret. Poignet actif sur PIN 5. Place le robot au HOME !");
}

// ================================
// Loop — pas de delay pour max vitesse
// ================================
void loop() {
  readSerialLines();

  if (newCommand) {
    applyLastCommand();
    newCommand = false;
  }

  // Vérification périodique des erreurs (toutes les 5 secondes)
  if (millis() - lastErrorCheck > 5000) {
    checkHardErrors();
    lastErrorCheck = millis();
  }
}

// ================================
// Lecture série
// ================================
void readSerialLines() {
  while (DEBUG_SERIAL.available() > 0) {
    char c = DEBUG_SERIAL.read();
    if (c == '\r')
      continue;

    if (c == '\n') {
      lineBuf[linePos] = '\0';
      if (lineBuf[0] == '?') {
        DEBUG_SERIAL.println("PONG");
      } else {
        parseCommandLine(lineBuf);
      }
      linePos = 0;
    } else {
      if (linePos < LINE_BUF_SIZE - 1) {
        lineBuf[linePos++] = c;
      } else {
        linePos = 0;
      }
    }
  }
}

// ================================
// Parsing CSV
// ================================
void parseCommandLine(const char *line) {
  char buf[128];
  strncpy(buf, line, 128);
  buf[127] = '\0';

  float vals[5];
  int count = 0;

  char *token = strtok(buf, ",");
  while (token != NULL && count < 5) {
    vals[count] = atof(token);
    count++;
    token = strtok(NULL, ",");
  }

  if (count < 5) {
    return; // Ignorer les lignes incomplètes
  }

  lastTheta1 = vals[0];
  lastTheta2 = vals[1];
  lastTheta3 = vals[2];
  lastPince = (vals[3] >= 0.5f);
  lastWristAngle = vals[4];

  newCommand = true;
  cmdCount++;

  // Debug léger : 1 message sur 30
  if (cmdCount % 30 == 0) {
    DEBUG_SERIAL.print("#");
    DEBUG_SERIAL.print(cmdCount);
    DEBUG_SERIAL.print(" [Ticks=");
    DEBUG_SERIAL.print(thetaToTicks(lastTheta1, REPOS_M1));
    DEBUG_SERIAL.print(",");
    DEBUG_SERIAL.print(thetaToTicks(lastTheta2, REPOS_M2));
    DEBUG_SERIAL.print(",");
    DEBUG_SERIAL.print(thetaToTicks(lastTheta3, REPOS_M3));
    DEBUG_SERIAL.print("] P=");
    DEBUG_SERIAL.print(lastPince ? "F" : "O");
    DEBUG_SERIAL.print(" W=");
    DEBUG_SERIAL.println(lastWristAngle);
  }
}

void applyLastCommand() {
  // 1) Moteurs Dynamixel
  dxl.setGoalPosition(ID_M1, thetaToTicks(lastTheta1, REPOS_M1));
  dxl.setGoalPosition(ID_M2, thetaToTicks(lastTheta2, REPOS_M2));
  dxl.setGoalPosition(ID_M3, thetaToTicks(lastTheta3, REPOS_M3));

  // 2) Servo pince — uniquement sur changement
  if (lastPince != currentPinceState) {
    currentPinceState = lastPince;
    pinceServo.writeMicroseconds(currentPinceState ? PULSE_FERMEE
                                                   : PULSE_OUVERTE);
  }

  // 3) Servo Poignet — uniquement sur changement significatif (> 0.5 deg)
  if (abs(lastWristAngle - currentWristAngle) > 0.5f) {
    currentWristAngle = lastWristAngle;

    // Mapping : 0° -> PULSE_WRIST_0_DEG, +90° -> PULSE_WRIST_90_DEG, -90° -> miroir
    float angle_clamped = currentWristAngle;
    if (angle_clamped > 90.0f)   // BUG CORRIGÉ : clamp positif
      angle_clamped = 90.0f;
    if (angle_clamped < -90.0f)  // clamp négatif
      angle_clamped = -90.0f;

    // Calcul proportionnel : 0° -> PULSE_WRIST_0_DEG, angle croissant -> pulse décroissant
    float range = (float)(PULSE_WRIST_0_DEG - PULSE_WRIST_90_DEG); // 1700 - 550 = 1150
    float pulse = (float)PULSE_WRIST_0_DEG - (angle_clamped * (range / 90.0f));

    // Bornes physiques : 550 (max positif) à 2850 (max négatif, symétrique)
    int pulseLow  = PULSE_WRIST_90_DEG;                   // 550
    int pulseHigh = PULSE_WRIST_0_DEG + (int)range;       // 1700 + 1150 = 2850
    int finalPulse = constrain((int)pulse, pulseLow, pulseHigh);
    wristServo.writeMicroseconds(finalPulse);
  }
}

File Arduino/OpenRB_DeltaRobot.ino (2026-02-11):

#include <Dynamixel2Arduino.h>

// ================================
// Configuration matérielle
// ================================

// Adapter ces définitions à ta carte OpenRB si besoin.
// - DEBUG_SERIAL : lien USB-C vers le PC (là où arrivent les lignes Python)
// - DXL_SERIAL   : bus Dynamixel (ports 3-pin)
#define DEBUG_SERIAL Serial
#define DXL_SERIAL   Serial1

// IDs des moteurs (à adapter à TON robot)
const uint8_t ID_M1    = 1;
const uint8_t ID_M2    = 2;
const uint8_t ID_M3    = 3;
const uint8_t ID_PINCE = 4;   // ou 0/255 si la pince n'est pas un Dynamixel

// Exemple pour Dynamixel 12 bits (4095 ticks par tour).
// Adapte à ton modèle (voir datasheet).
const float TICKS_PER_REV = 4095.0f;

Dynamixel2Arduino dxl(DXL_SERIAL);

// ================================
// Buffer & état courant
// ================================

const size_t LINE_BUF_SIZE = 64;
char   lineBuf[LINE_BUF_SIZE];
size_t linePos = 0;

// Dernière commande reçue
float lastTheta1 = 0.0f;
float lastTheta2 = 0.0f;
float lastTheta3 = 0.0f;
bool  lastPince  = false;

// ================================
// Initialisation
// ================================

void setup() {
  // USB vers PC (reçoit les lignes envoyées par PieToArduino.py)
  DEBUG_SERIAL.begin(115200);
  while (!DEBUG_SERIAL) {
    ; // attendre l'ouverture du port
  }

  // Bus Dynamixel
  DXL_SERIAL.begin(57600);
  dxl.begin(57600);
  dxl.setPortProtocolVersion(2.0);

  // Met tous les moteurs en mode Position
  dxl.torqueOff(ID_M1);
  dxl.torqueOff(ID_M2);
  dxl.torqueOff(ID_M3);
  dxl.torqueOff(ID_PINCE);

  dxl.setOperatingMode(ID_M1, OP_POSITION);
  dxl.setOperatingMode(ID_M2, OP_POSITION);
  dxl.setOperatingMode(ID_M3, OP_POSITION);
  dxl.setOperatingMode(ID_PINCE, OP_POSITION); // si la pince est aussi un Dynamixel

  dxl.torqueOn(ID_M1);
  dxl.torqueOn(ID_M2);
  dxl.torqueOn(ID_M3);
  dxl.torqueOn(ID_PINCE);

  DEBUG_SERIAL.println("OpenRB Delta Robot ready (theta1,theta2,theta3,pince) over USB.");
}

// ================================
// Boucle principale
// ================================

void loop() {
  // 1) Lire les lignes arrivant depuis le PC (USB)
  readSerialLines();

  // 2) Appliquer en continu la dernière commande reçue
  applyLastCommand();

  // Fréquence de contrôle ~200 Hz
  delay(5);
}

// ================================
// Lecture série & parsing
// ================================

// Accumule les caractères reçus sur DEBUG_SERIAL
// et appelle parseCommandLine() à chaque fin de ligne '\n'.
void readSerialLines() {
  while (DEBUG_SERIAL.available() > 0) {
    char c = DEBUG_SERIAL.read();

    if (c == '\r') {
      // On ignore les retours chariot éventuels
      continue;
    }

    if (c == '\n') {
      // Fin de ligne : traiter le buffer courant
      lineBuf[linePos] = '\0';
      parseCommandLine(lineBuf);
      linePos = 0;  // reset pour la prochaine ligne
    } else {
      if (linePos < LINE_BUF_SIZE - 1) {
        lineBuf[linePos++] = c;
      } else {
        // Ligne trop longue : on reset pour éviter les débordements
        linePos = 0;
      }
    }
  }
}

// Parse une ligne du type : "theta1,theta2,theta3,pince"
// où les thetas sont envoyés par Python en RADIANS,
// et pince vaut 0 (ouvert) ou 1 (fermé).
void parseCommandLine(const char* line) {
  char buf[LINE_BUF_SIZE];
  strncpy(buf, line, LINE_BUF_SIZE);
  buf[LINE_BUF_SIZE - 1] = '\0';

  float vals[4];
  int   count = 0;

  char* token = strtok(buf, ",");
  while (token != NULL && count < 4) {
    vals[count] = atof(token);
    count++;
    token = strtok(NULL, ",");
  }

  if (count < 4) {
    DEBUG_SERIAL.print("Ligne invalide (attendu 4 valeurs) : ");
    DEBUG_SERIAL.println(line);
    return;
  }

  // Angles en radians reçus depuis Python
  lastTheta1 = vals[0];
  lastTheta2 = vals[1];
  lastTheta3 = vals[2];
  lastPince  = (vals[3] >= 0.5f);

  // Debug
  DEBUG_SERIAL.print("Cmd: ");
  DEBUG_SERIAL.print(lastTheta1); DEBUG_SERIAL.print(", ");
  DEBUG_SERIAL.print(lastTheta2); DEBUG_SERIAL.print(", ");
  DEBUG_SERIAL.print(lastTheta3); DEBUG_SERIAL.print(", pince=");
  DEBUG_SERIAL.println(lastPince ? "1" : "0");
}

// ================================
// Application de la commande
// ================================

void applyLastCommand() {
  // Conversion radians -> degrés
  float theta1_deg = lastTheta1 * 180.0f / PI;
  float theta2_deg = lastTheta2 * 180.0f / PI;
  float theta3_deg = lastTheta3 * 180.0f / PI;

  // Conversion degrés -> ticks (0..TICKS_PER_REV)
  int32_t pos1 = (int32_t)(theta1_deg / 360.0f * TICKS_PER_REV);
  int32_t pos2 = (int32_t)(theta2_deg / 360.0f * TICKS_PER_REV);
  int32_t pos3 = (int32_t)(theta3_deg / 360.0f * TICKS_PER_REV);

  dxl.setGoalPosition(ID_M1, pos1);
  dxl.setGoalPosition(ID_M2, pos2);
  dxl.setGoalPosition(ID_M3, pos3);

  // Pince : exemple simple avec deux positions (adapter aux limites réelles)
  if (lastPince) {
    dxl.setGoalPosition(ID_PINCE, 3000);  // Fermé
  } else {
    dxl.setGoalPosition(ID_PINCE, 1500);  // Ouvert
  }
}

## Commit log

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2026-01-29 Copy de Git personnel à Git de projet (code de plannification de trajectoire)
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2026-02-03 Change prints to differ motors
2026-02-11 recherche de distance focale (3.4)
2026-02-11 real position in cm using calibration
2026-02-25 test main update
    [pyvenv.cfg]
2026-02-25 y'a eu un bug
    [OpenRB_DeltaRobot.ino, PieToArduino.py, picam2_focus_manual.py]
2026-03-11 Removed unused `python_hands_gst_gi.py` file, updated import path for `detect_colored_blocks` in `stable_block_output.py`, added new HSV calibration script and README, and refactored file paths in va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
2026-03-11 feat: add live square detection with strict colored block detection
    - Implemented a new script for live video processing using GStreamer.
    - Added functionality to detect uniform and rectangular colored blocks in real-time.
    - Introduced parameters for color calibration using HSV ranges.
    - Included utility functions for image processing and visualization.
    - Enabled pixel-to-world coordinate mapping for detected blocks.
    - Added interactive tuning options for detection parameters during runtime.
2026-03-11 refactor: streamline block detection logic and enhance flash filter application
2026-03-11 refactor: enhance flash filter application and improve code readability
2026-03-11 refactor: update strength parameter and enhance color key mappings in calibration and new colors
2026-03-18 refactor: enhance block detection with additional filtering and dimension checks
2026-03-18 Update MouvementConnecte.py
    le file est de retour
2026-03-18 Add real-world dimension calculation for detected blocks and optional LEGO filter
2026-03-18 connecté a la cam - deplacement
2026-03-25 Refactored HSV calibration script for improved functionality and updated README for clarity.
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2026-03-25 modif le feed de la cam
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2026-03-25 invert X coordinate in current_blocks for accurate positioning
2026-03-25 Add structure to README with sections for introduction, vision, trajectory planning, inverse kinematics, operation sequence, and conclusion
2026-03-25 clean file
    [pyvenv.cfg]
2026-03-25 Refactor block detection logic to improve color filtering and add dominant color fraction calculation
2026-03-25 Remove obsolete block detection script with filter
2026-04-01 Update camera center calculation in homography saving process
2026-04-01 Hub adapation et code de OpenRb avec la nouvelle pince
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2026-04-09 Gros problème de mise à jour OS (réglé, on a perdu la détection de main)
2026-04-09 changement pour le homing et le scaling
2026-04-09 changement de longueur segments
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2026-04-10 changemnent de la vitesse
2026-04-16 Update wrist angle offset to correct camera alignment
2026-04-16 Update wrist angle offset for improved camera alignment
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2026-04-16 Adjust drop height and slot offset for improved positioning
2026-04-16 patch update bloc de lUI
2026-04-16 Update global speed parameters for improved joint and approach movements
2026-04-16 Adjust drop radius and slot offset for improved positioning accuracy
2026-04-16 Fix slot position calculations for drop bac coordinates
2026-04-16 offset pince des le depart
2026-04-16 Update y-axis limits in draw_route_2D_v2 for improved trajectory visualization
2026-04-16 Update wrist angle offset for improved calibration accuracy
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2026-04-16 ajuster les vitesses pour les modes RAPIDE et CHILL
2026-04-16 ajuster l'angle de décalage de la pince pour améliorer la précision de détection
2026-04-16 ajuster la vitesse de retour au home pour le mode CHILL
2026-04-16 modification de la section sélection de bloc de l'UI
2026-04-16 Changement de noms de fichiers
2026-04-16 Update wrist angle offset for camera alignment
2026-04-16 changement gestion de l'angle
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2026-04-18 Remove Direct Kinematics and Trajectory Planning sections
    Removed sections on Direct Kinematics and Trajectory Planning from the kinematics documentation.
2026-04-18 Revise BOM section with clearer titles and images
    Updated the BOM section to clarify component names and added images for better visualization.
2026-04-18 Fix typo in camera description in hardware.md
2026-04-18 Add CAD documentation for QuickBrick Delta project
    Added CAD files documentation for QuickBrick Delta project, including file structure, available formats, and 3D printing assembly details.
2026-04-18 Update readme-cad.md with Pince details
    Added details for new 'Pince' section with STL files.
2026-04-18 Revise CAD readme section titles and notes
    Updated the section title from 'Assemblage robot' to 'Bras robotique' and added a note about assembly screws.
2026-04-18 Update links in CAD readme file
2026-04-18 Update CAD readme with assembly details and images
    Added assembly images and STL file references for various components including robotic arms, acrylic plates, and other parts.
2026-04-18 Fix formatting and add assembly notes in readme
    Correct formatting issues and add missing notes section.
2026-04-18 Add DXF format and new components for laser cutting
    Added DXF format support and new parts for laser cutting.
2026-04-19 Update images and sections in readme-cad.md
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2026-04-19 Update README.md to include path for CAD files
2026-04-19 Revise laser cut shelf details and images
    Updated the laser cut shelf section with new images and details for various parts, including STL and DXF files.
2026-04-19 Add plaque-plancher-secondaire.dxf file
    [plaque-plancher-secondaire.dxf]
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

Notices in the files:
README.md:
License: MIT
